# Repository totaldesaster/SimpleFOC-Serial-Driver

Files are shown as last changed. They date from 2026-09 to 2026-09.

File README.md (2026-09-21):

# SimpleFOC-Serial-Driver
Advanced dual BLDC driver modules, designed to be controlled from a trajectory controller over a serial connection. Features a compact high power design with two stacked PCBs. While the top PCB focuses on motor driving, the bottom PCB serves as the controller and interface board.



Work in Progress, will be updated as more information and tests become available!

# Base Board (RP2350)
BaseBoard
The base board acts as a carrier for power boards and contains the microcontroller, communications and programming interfaces, and power input circuits. It shares power with top-mounted driver boards over the standoffs in the mounting holes. It's equipped with:  

- RP2354B, Dual Cortex-M33 or RISC-V processors at 150MHz
- THVD1424, communication over RS-485 or RS-422 at up to 10MHz
- Input voltage and current monitoring
- Two Encoder connections with I2C interfaces
- External connections to power, RS-422/485 and TTL UART

# Dual BLDC driver board
DualShield
Featuring two BLDC drivers and an auxiliary circuit to dissipate braking energy, the Dual BLDC board is able to drive low to medium power BLDCs at up to 7 amps. Peak currents may be far higher (not yet tested).  

- Two DRV8323S (SPI configuration) or DRV8323H (hard-coded) BLDC drivers
- Medium-Power HSBB6066 MOSFETs
- Onboard brake resistor able to dissipate ~5 watts
- Onboard thermistor to measure the board's temperature

# High-Power BLDC driver board
PowerShield
Equipped with bigger MOSFETs and connection points for an external brake resistor and power supply, this board is able to drive a much higher power motor.  

- DRV8323S BLDC driver
- 160A rated Infineon OptiMOS MOSFETs, continuous power limited by thermals (not yet tested)$
- Auxiliary output for external brake resistor
- Onboard thermistor to measure the board's temperature

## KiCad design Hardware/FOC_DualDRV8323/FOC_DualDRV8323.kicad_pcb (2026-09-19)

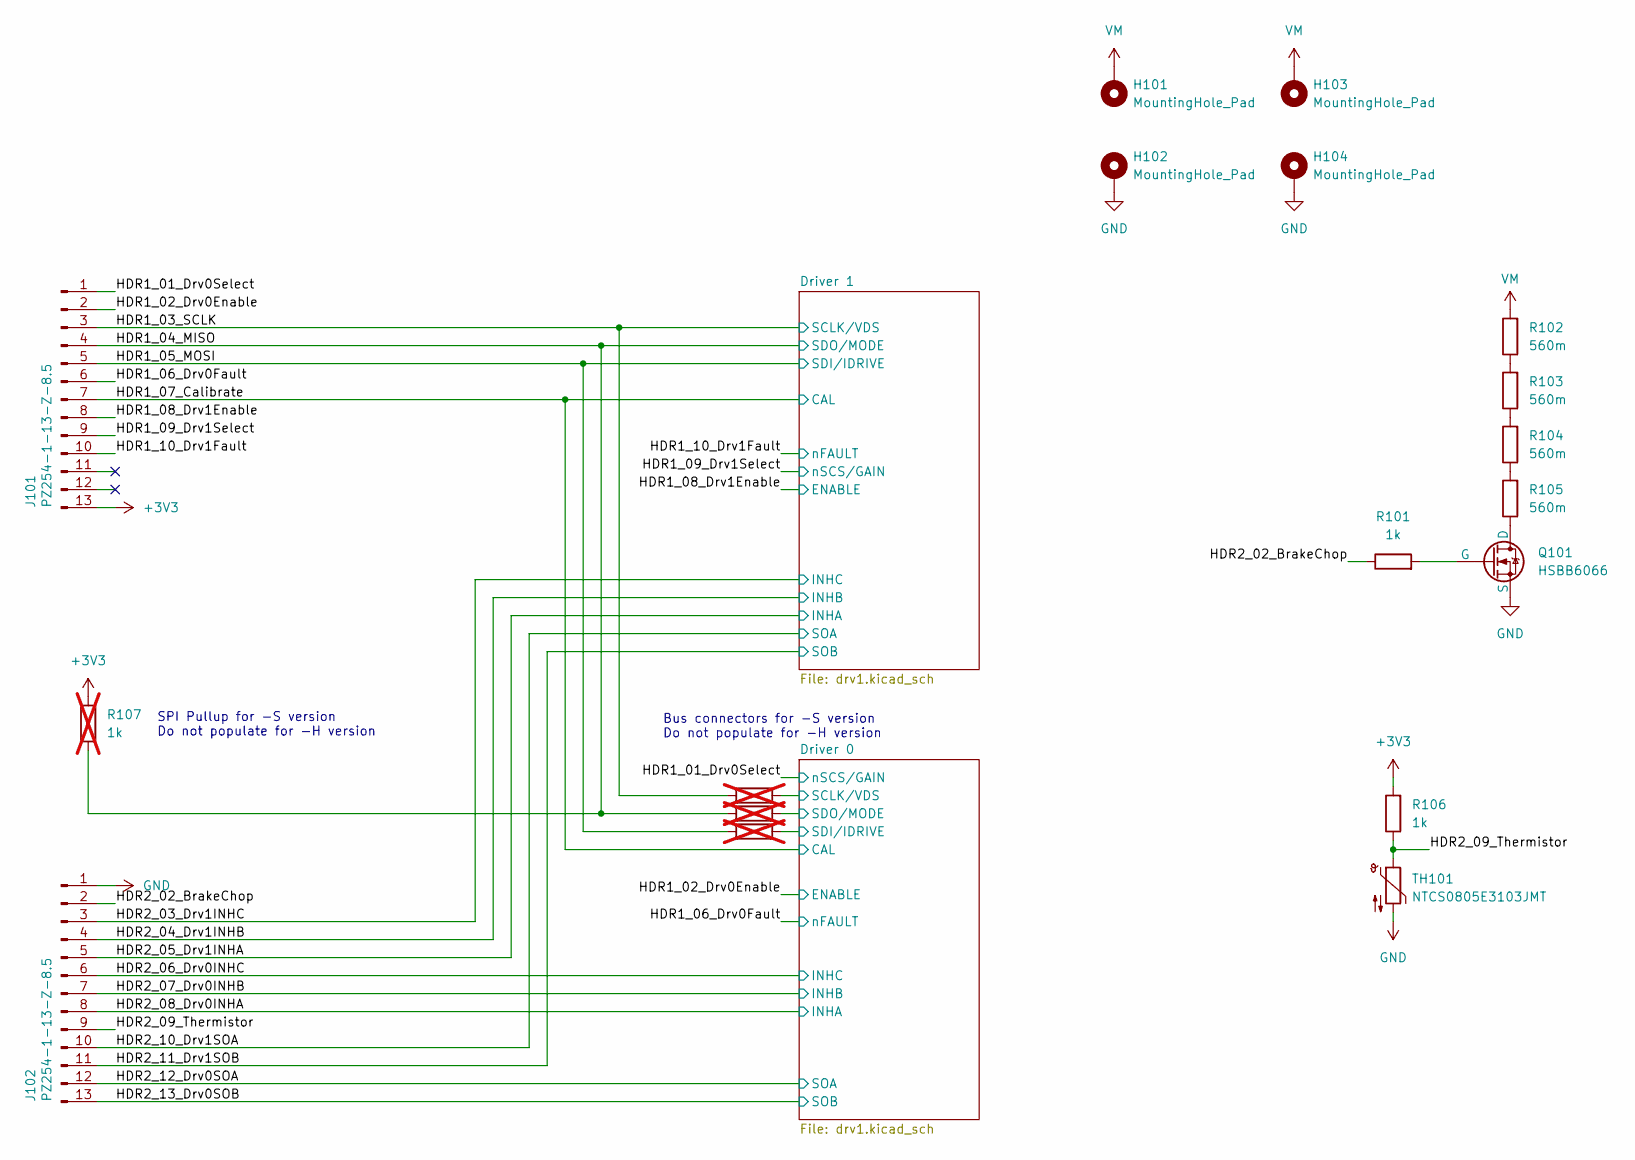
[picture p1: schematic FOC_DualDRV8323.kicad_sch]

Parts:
H101, H102, H103, H104: MountingHole_Pad; MountingHole_3.2mm_M3_Pad_Via
J101: PZ254-1-13-Z-8.5; PinHeader_1x13_P2.54mm_Vertical_SMD_Pin1Left
J102: PZ254-1-13-Z-8.5; PinHeader_1x13_P2.54mm_Vertical_SMD_Pin1Right
Q101: HSBB6066; VSON-8_3.3x3.3mm_P0.65mm_NexFET
R101, R106: 1k; R_0603_1608Metric
R102, R103, R104, R105: 560m; R_2512_6332Metric
R107: 1k; R_0603_1608Metric; not fitted
R108, R109, R110: 0; R_0603_1608Metric; not fitted
TH101: NTCS0805E3103JMT; R_0805_2012Metric

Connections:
+3V3: J101.13, R106.2, R107.2
/Driver 0/SCLK/VDS: R108.1; also elsewhere on the board
/Driver 0/SDI/IDRIVE: R110.1; also elsewhere on the board
/Driver 0/SDO/MODE: R109.1; also elsewhere on the board
/HDR1_01_Drv0Select: J101.1; also elsewhere on the board
/HDR1_02_Drv0Enable: J101.2; also elsewhere on the board
/HDR1_03_SCLK: J101.3, R108.2; also elsewhere on the board
/HDR1_04_MISO: J101.4, R107.1, R109.2; also elsewhere on the board
/HDR1_05_MOSI: J101.5, R110.2; also elsewhere on the board
/HDR1_06_Drv0Fault: J101.6; also elsewhere on the board
/HDR1_07_Calibrate: J101.7; also elsewhere on the board
/HDR1_08_Drv1Enable: J101.8; also elsewhere on the board
/HDR1_09_Drv1Select: J101.9; also elsewhere on the board
/HDR1_10_Drv1Fault: J101.10; also elsewhere on the board
/HDR2_02_BrakeChop: J102.2, R101.1
/HDR2_03_Drv1INHC: J102.3; also elsewhere on the board
/HDR2_04_Drv1INHB: J102.4; also elsewhere on the board
/HDR2_05_Drv1INHA: J102.5; also elsewhere on the board
/HDR2_06_Drv0INHC: J102.6; also elsewhere on the board
/HDR2_07_Drv0INHB: J102.7; also elsewhere on the board
/HDR2_08_Drv0INHA: J102.8; also elsewhere on the board
/HDR2_09_Thermistor: J102.9, R106.1, TH101.1
/HDR2_10_Drv1SOA: J102.10; also elsewhere on the board
/HDR2_11_Drv1SOB: J102.11; also elsewhere on the board
/HDR2_12_Drv0SOA: J102.12; also elsewhere on the board
/HDR2_13_Drv0SOB: J102.13; also elsewhere on the board
GND: H102.1 (1_1), H104.1 (1_1), J102.1, Q101.3 (S), TH101.2; also elsewhere on the board
unnamed: Q101.1 (D), R105.1
unnamed: Q101.2 (G), R101.2
unnamed: R102.1, R103.2
unnamed: R103.1, R104.2
unnamed: R104.1, R105.2
VM: H101.1 (1_1), H103.1 (1_1), R102.2; also elsewhere on the board

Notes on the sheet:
Bus connectors for -S version Do not populate for -H version
SPI Pullup for -S version Do not populate for -H version

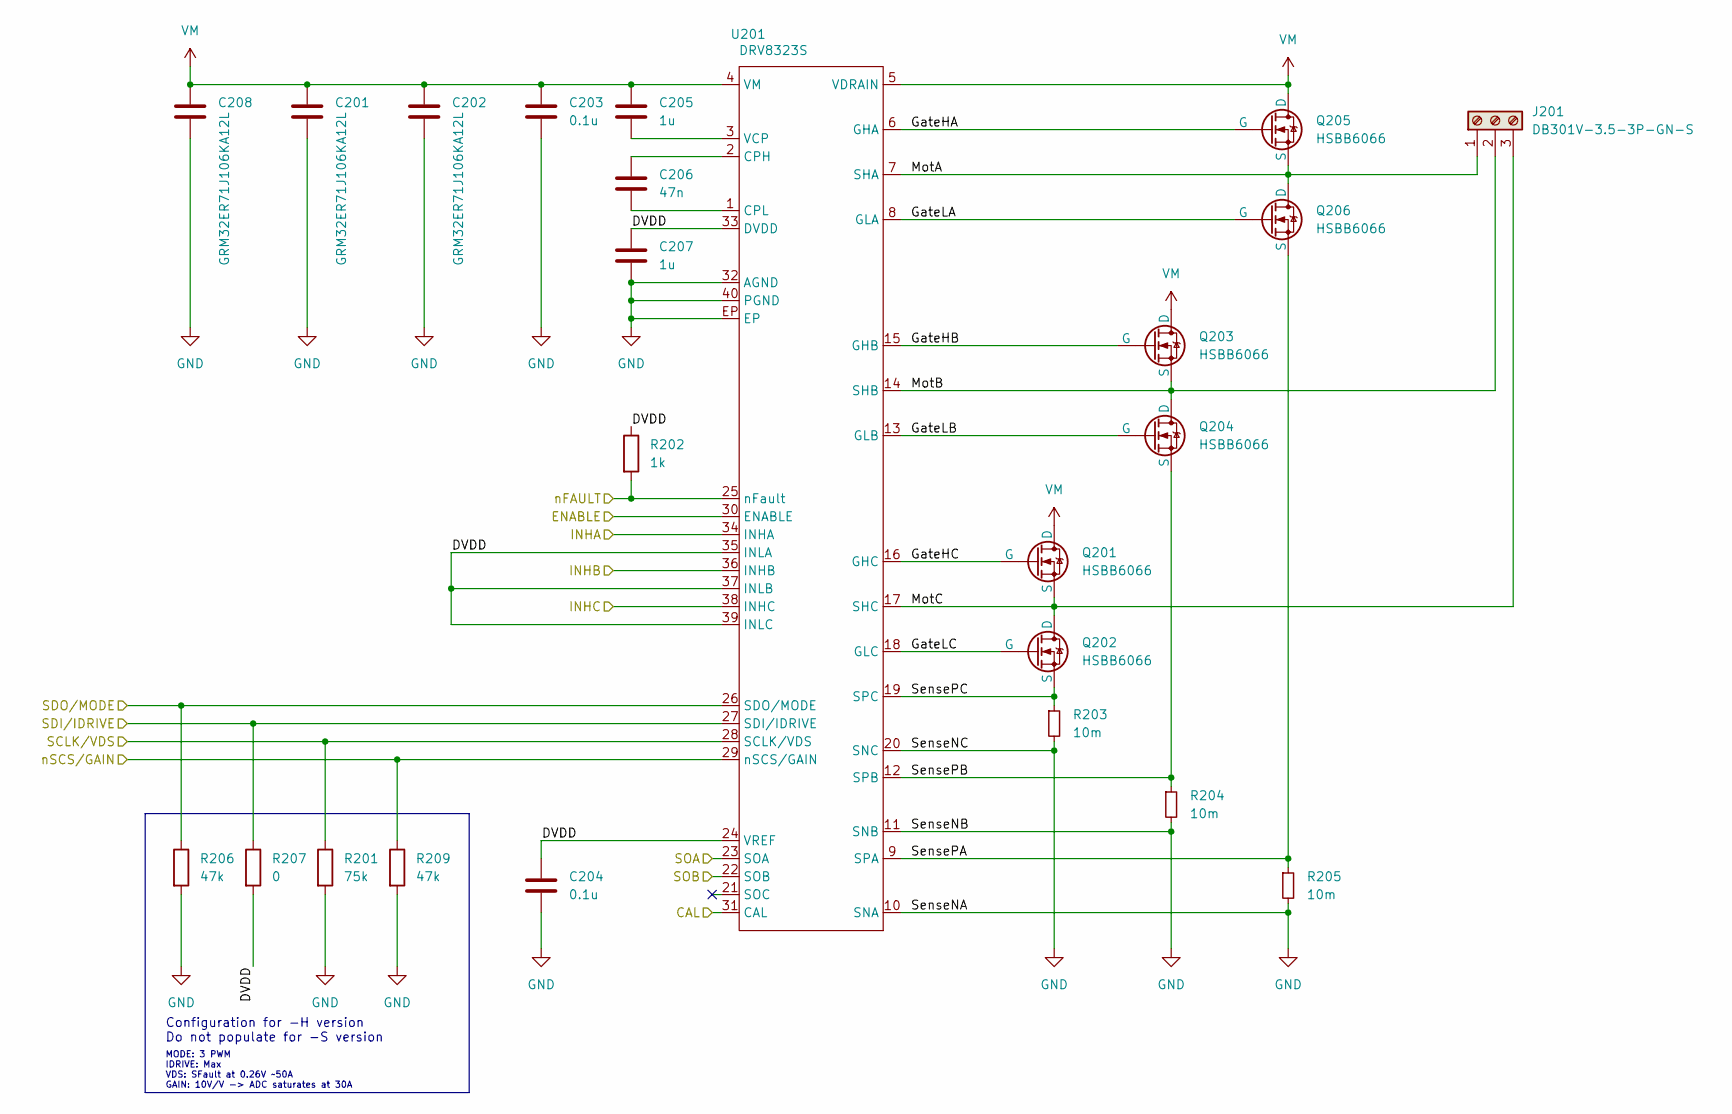
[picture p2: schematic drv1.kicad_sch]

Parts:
C201, C202, C208: GRM32ER71J106KA12L; C_1210_3225Metric
C203, C204: 0.1u; C_0603_1608Metric
C205, C207: 1u; C_0603_1608Metric
C206: 47n; C_0603_1608Metric
J201: DB301V-3.5-3P-GN-S; TerminalBlock_Phoenix_PT-1,5-3-3.5-H_1x03_P3.50mm_Horizontal
Q201, Q202, Q203, Q204, Q205, Q206: HSBB6066; VSON-8_3.3x3.3mm_P0.65mm_NexFET
R201: 75k; R_0603_1608Metric
R202: 1k; R_0603_1608Metric
R203, R204, R205: 10m; R_1206_3216Metric
R206, R209: 47k; R_0603_1608Metric
R207: 0; R_0603_1608Metric
U201: DRV8323S; Texas_RHA0040E_VQFN-40-1EP_6x6mm_P0.5mm_EP3.52x2.62mm

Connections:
/Driver 0/DVDD: C204.1, C207.1, R202.1, R207.2, U201.24 (VREF), U201.33 (DVDD), U201.35 (INLA), U201.37 (INLB), U201.39 (INLC)
/Driver 0/GateHA: Q205.2 (G), U201.6 (GHA)
/Driver 0/GateHB: Q203.2 (G), U201.15 (GHB)
/Driver 0/GateHC: Q201.2 (G), U201.16 (GHC)
/Driver 0/GateLA: Q206.2 (G), U201.8 (GLA)
/Driver 0/GateLB: Q204.2 (G), U201.13 (GLB)
/Driver 0/GateLC: Q202.2 (G), U201.18 (GLC)
/Driver 0/MotA: J201.1, Q205.3 (S), Q206.1 (D), U201.7 (SHA)
/Driver 0/MotB: J201.2, Q203.3 (S), Q204.1 (D), U201.14 (SHB)
/Driver 0/MotC: J201.3, Q201.3 (S), Q202.1 (D), U201.17 (SHC)
/Driver 0/SCLK/VDS: R201.1, U201.28 (SCLK/VDS); also elsewhere on the board
/Driver 0/SDI/IDRIVE: R207.1, U201.27 (SDI/IDRIVE); also elsewhere on the board
/Driver 0/SDO/MODE: R206.1, U201.26 (SDO/MODE); also elsewhere on the board
/Driver 0/SensePA: Q206.3 (S), R205.1, U201.9 (SPA)
/Driver 0/SensePB: Q204.3 (S), R204.1, U201.12 (SPB)
/Driver 0/SensePC: Q202.3 (S), R203.1, U201.19 (SPC)
/HDR1_01_Drv0Select: R209.1, U201.29 (nSCS/GAIN); also elsewhere on the board
/HDR1_02_Drv0Enable: U201.30 (ENABLE); also elsewhere on the board
/HDR1_06_Drv0Fault: R202.2, U201.25 (nFault); also elsewhere on the board
/HDR1_07_Calibrate: U201.31 (CAL); also elsewhere on the board
/HDR2_06_Drv0INHC: U201.38 (INHC); also elsewhere on the board
/HDR2_07_Drv0INHB: U201.36 (INHB); also elsewhere on the board
/HDR2_08_Drv0INHA: U201.34 (INHA); also elsewhere on the board
/HDR2_12_Drv0SOA: U201.23 (SOA); also elsewhere on the board
/HDR2_13_Drv0SOB: U201.22 (SOB); also elsewhere on the board
GND: C201.2, C202.2, C203.2, C204.2, C207.2, C208.2, R201.2, R203.2, R204.2, R205.2, R206.2, R209.2, U201.10 (SNA), U201.11 (SNB), U201.20 (SNC), U201.32 (AGND), U201.40 (PGND), U201.EP; also elsewhere on the board
unnamed: C206.1, U201.2 (CPH)
unnamed: C206.2, U201.1 (CPL)
unnamed: C205.2, U201.3 (VCP)
VM: C201.1, C202.1, C203.1, C205.1, C208.1, Q201.1 (D), Q203.1 (D), Q205.1 (D), U201.4 (VM), U201.5 (VDRAIN); also elsewhere on the board

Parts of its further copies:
C301, C302, C308: GRM32ER71J106KA12L; C_1210_3225Metric
C303, C304: 0.1u; C_0603_1608Metric
C305, C307: 1u; C_0603_1608Metric
C306: 47n; C_0603_1608Metric
J301: DB301V-3.5-3P-GN-S; TerminalBlock_Phoenix_PT-1,5-3-3.5-H_1x03_P3.50mm_Horizontal
Q301, Q302, Q303, Q304, Q305, Q306: HSBB6066; VSON-8_3.3x3.3mm_P0.65mm_NexFET
R301: 75k; R_0603_1608Metric
R302: 1k; R_0603_1608Metric
R303, R304, R305: 10m; R_1206_3216Metric
R306, R309: 47k; R_0603_1608Metric
R307: 0; R_0603_1608Metric
U301: DRV8323S; Texas_RHA0040E_VQFN-40-1EP_6x6mm_P0.5mm_EP3.52x2.62mm

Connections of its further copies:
/Driver 1/DVDD: C304.1, C307.1, R302.1, R307.2, U301.24 (VREF), U301.33 (DVDD), U301.35 (INLA), U301.37 (INLB), U301.39 (INLC)
/Driver 1/GateHA: Q305.2 (G), U301.6 (GHA)
/Driver 1/GateHB: Q303.2 (G), U301.15 (GHB)
/Driver 1/GateHC: Q301.2 (G), U301.16 (GHC)
/Driver 1/GateLA: Q306.2 (G), U301.8 (GLA)
/Driver 1/GateLB: Q304.2 (G), U301.13 (GLB)
/Driver 1/GateLC: Q302.2 (G), U301.18 (GLC)
/Driver 1/MotA: J301.1, Q305.3 (S), Q306.1 (D), U301.7 (SHA)
/Driver 1/MotB: J301.2, Q303.3 (S), Q304.1 (D), U301.14 (SHB)
/Driver 1/MotC: J301.3, Q301.3 (S), Q302.1 (D), U301.17 (SHC)
/Driver 1/SensePA: Q306.3 (S), R305.1, U301.9 (SPA)
/Driver 1/SensePB: Q304.3 (S), R304.1, U301.12 (SPB)
/Driver 1/SensePC: Q302.3 (S), R303.1, U301.19 (SPC)
/HDR1_03_SCLK: R301.1, U301.28 (SCLK/VDS); also elsewhere on the board
/HDR1_04_MISO: R306.1, U301.26 (SDO/MODE); also elsewhere on the board
/HDR1_05_MOSI: R307.1, U301.27 (SDI/IDRIVE); also elsewhere on the board
/HDR1_07_Calibrate: U301.31 (CAL); also elsewhere on the board
/HDR1_08_Drv1Enable: U301.30 (ENABLE); also elsewhere on the board
/HDR1_09_Drv1Select: R309.1, U301.29 (nSCS/GAIN); also elsewhere on the board
/HDR1_10_Drv1Fault: R302.2, U301.25 (nFault); also elsewhere on the board
/HDR2_03_Drv1INHC: U301.38 (INHC); also elsewhere on the board
/HDR2_04_Drv1INHB: U301.36 (INHB); also elsewhere on the board
/HDR2_05_Drv1INHA: U301.34 (INHA); also elsewhere on the board
/HDR2_10_Drv1SOA: U301.23 (SOA); also elsewhere on the board
/HDR2_11_Drv1SOB: U301.22 (SOB); also elsewhere on the board
GND: C301.2, C302.2, C303.2, C304.2, C307.2, C308.2, R301.2, R303.2, R304.2, R305.2, R306.2, R309.2, U301.10 (SNA), U301.11 (SNB), U301.20 (SNC), U301.32 (AGND), U301.40 (PGND); also elsewhere on the board
unnamed: C306.1, U301.2 (CPH)
unnamed: C306.2, U301.1 (CPL)
unnamed: C305.2, U301.3 (VCP)
VM: C301.1, C302.1, C303.1, C305.1, C308.1, Q301.1 (D), Q303.1 (D), Q305.1 (D), U301.4 (VM), U301.5 (VDRAIN); also elsewhere on the board

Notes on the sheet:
Configuration for -H version Do not populate for -S version
MODE: 3 PWM IDRIVE: Max VDS: SFault at 0.26V ~50A GAIN: 10V/V -> ADC saturates at 30A

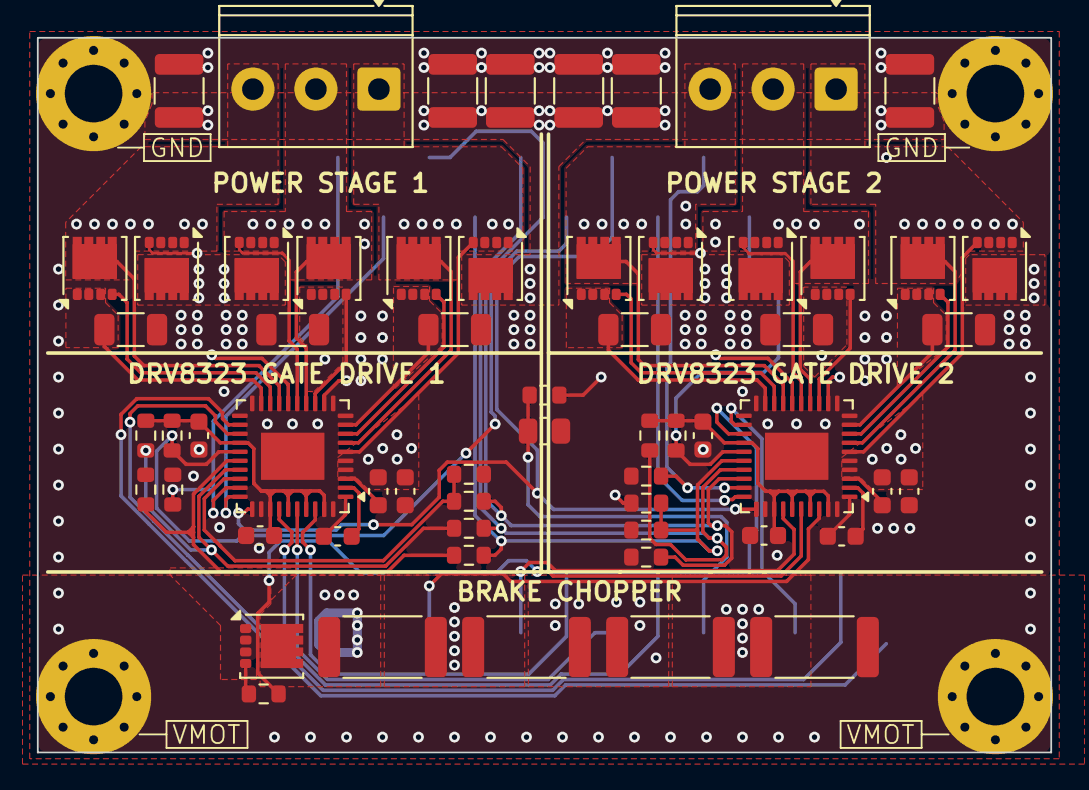
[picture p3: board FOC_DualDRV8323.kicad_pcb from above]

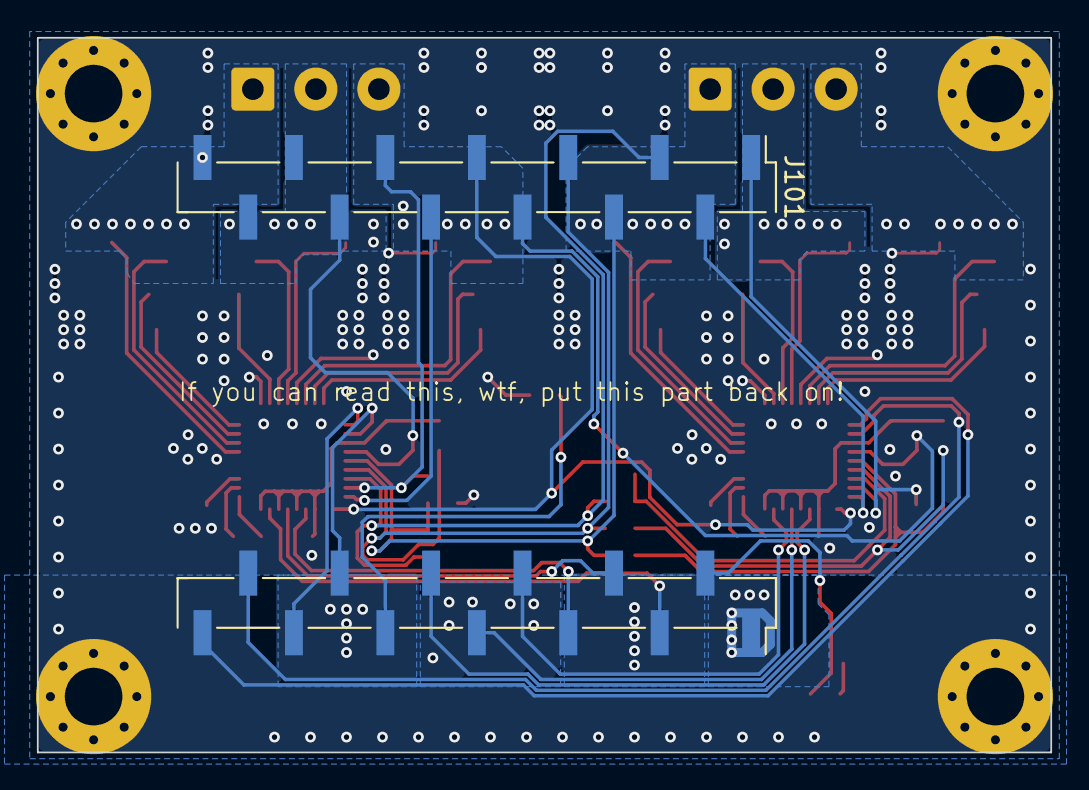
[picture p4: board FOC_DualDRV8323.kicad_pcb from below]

Board: 4 copper layers, 56.3 x 39.7 mm, 66 parts (2 on the bottom side), 65 nets.

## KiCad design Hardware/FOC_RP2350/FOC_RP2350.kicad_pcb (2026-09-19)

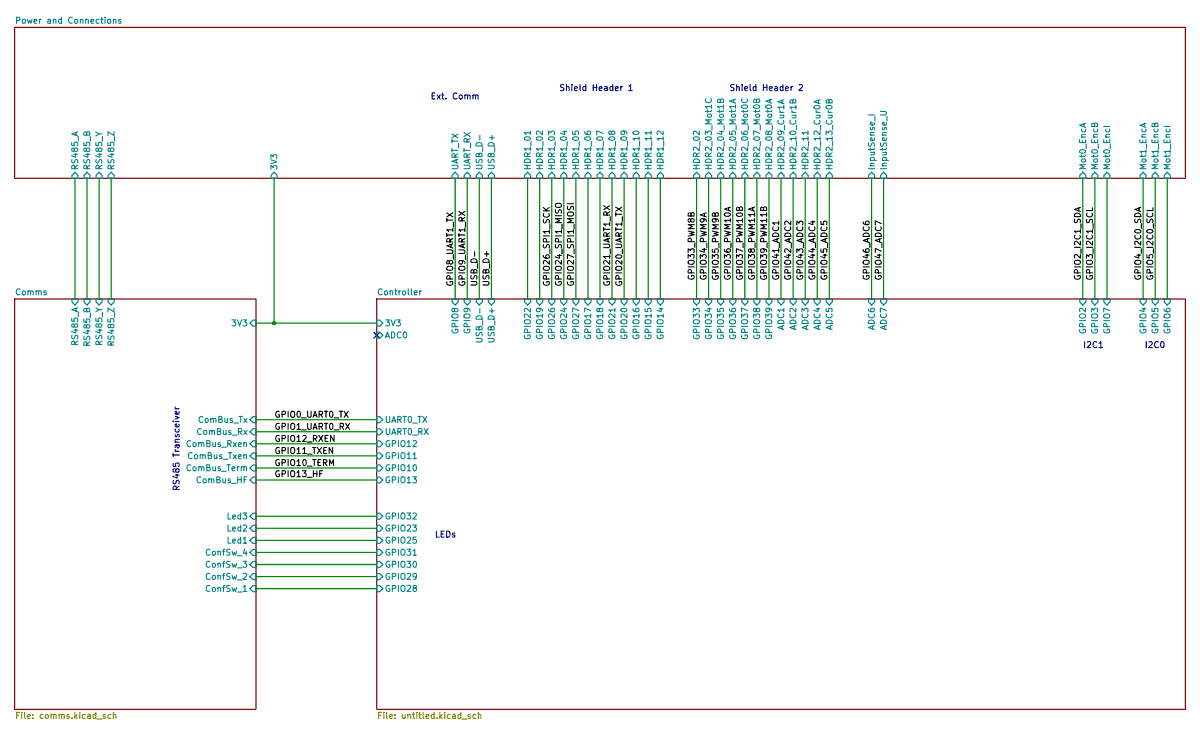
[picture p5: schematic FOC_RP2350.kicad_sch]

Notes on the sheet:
I2C1
I2C0
Shield Header 2
Ext. Comm
LEDs
RS485 Transceiver
Shield Header 1

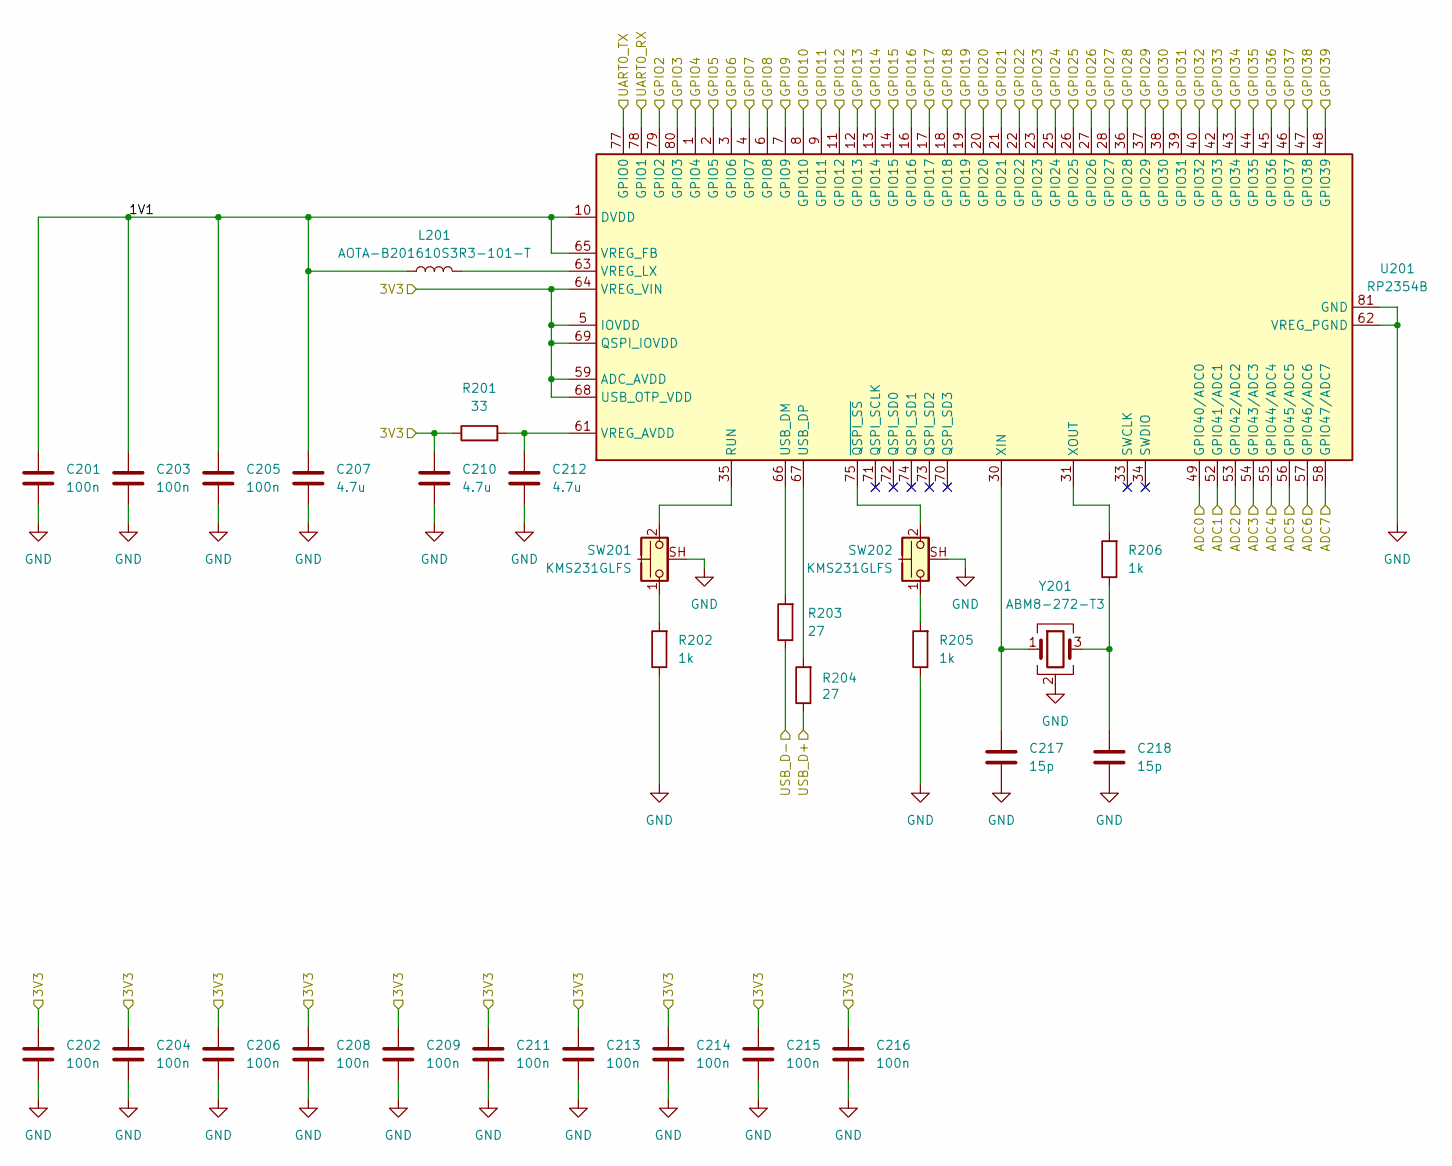
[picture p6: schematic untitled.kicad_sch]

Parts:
C201, C202, C203, C204, C205, C206, C208, C209, C211, C213, C214, C215, C216: 100n; C_0402_1005Metric
C207, C210, C212: 4.7u; C_0402_1005Metric
C217, C218: 15p; C_0402_1005Metric
L201: AOTA-B201610S3R3-101-T; L_Changjiang_FTC201607S
R201: 33; R_0402_1005Metric
R202, R205: 1k; R_0805_2012Metric
R203, R204: 27; R_0603_1608Metric
R206: 1k; R_0402_1005Metric
SW201, SW202: KMS231GLFS; SW_SPST_CK_KMS2xxGP
U201: RP2354B; QFN-80-1EP_10x10mm_P0.4mm_EP3.4x3.4mm
Y201: ABM8-272-T3; Crystal_SMD_Abracon_ABM8G-4Pin_3.2x2.5mm

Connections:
/Comms/3V3: C202.1, C204.1, C206.1, C208.1, C209.1, C210.1, C211.1, C213.1, C214.1, C215.1, C216.1, R201.1, U201.5 (IOVDD), U201.15 (IOVDD), U201.24 (IOVDD), U201.29 (IOVDD), U201.41 (IOVDD), U201.50 (IOVDD), U201.59 (ADC_AVDD), U201.60 (IOVDD), U201.64 (VREG_VIN), U201.68 (USB_OTP_VDD), U201.69 (QSPI_IOVDD), U201.76 (IOVDD); also elsewhere on the board
/Comms/ComBus_HF: U201.12 (GPIO13); also elsewhere on the board
/Comms/ConfSw_1: U201.36 (GPIO28); also elsewhere on the board
/Comms/ConfSw_2: U201.37 (GPIO29); also elsewhere on the board
/Comms/ConfSw_3: U201.38 (GPIO30); also elsewhere on the board
/Comms/ConfSw_4: U201.39 (GPIO31); also elsewhere on the board
/Comms/Led1: U201.26 (GPIO25); also elsewhere on the board
/Comms/Led2: U201.23 (GPIO23); also elsewhere on the board
/Comms/Led3: U201.40 (GPIO32); also elsewhere on the board
/Controller/1V1: C201.1, C203.1, C205.1, C207.1, L201.1, U201.10 (DVDD), U201.32 (DVDD), U201.51 (DVDD), U201.65 (VREG_FB)
/Controller/ADC0: U201.49 (GPIO40/ADC0)
/Controller/GPIO6: U201.3 (GPIO6); also elsewhere on the board
/Controller/GPIO7: U201.4 (GPIO7); also elsewhere on the board
/Controller/GPIO14: U201.13 (GPIO14); also elsewhere on the board
/Controller/GPIO15: U201.14 (GPIO15); also elsewhere on the board
/Controller/GPIO16: U201.16 (GPIO16); also elsewhere on the board
/Controller/GPIO17: U201.17 (GPIO17); also elsewhere on the board
/Controller/GPIO18: U201.18 (GPIO18); also elsewhere on the board
/Controller/GPIO19: U201.19 (GPIO19); also elsewhere on the board
/Controller/GPIO22: U201.22 (GPIO22); also elsewhere on the board
/GPIO0_UART0_TX: U201.77 (GPIO0); also elsewhere on the board
/GPIO1_UART0_RX: U201.78 (GPIO1); also elsewhere on the board
/GPIO2_I2C1_SDA: U201.79 (GPIO2); also elsewhere on the board
/GPIO3_I2C1_SCL: U201.80 (GPIO3); also elsewhere on the board
/GPIO4_I2C0_SDA: U201.1 (GPIO4); also elsewhere on the board
/GPIO5_I2C0_SCL: U201.2 (GPIO5); also elsewhere on the board
/GPIO8_UART1_TX: U201.6 (GPIO8); also elsewhere on the board
/GPIO9_UART1_RX: U201.7 (GPIO9); also elsewhere on the board
/GPIO10_TERM: U201.8 (GPIO10); also elsewhere on the board
/GPIO11_TXEN: U201.9 (GPIO11); also elsewhere on the board
/GPIO12_RXEN: U201.11 (GPIO12); also elsewhere on the board
/GPIO20_UART1_TX: U201.20 (GPIO20); also elsewhere on the board
/GPIO21_UART1_RX: U201.21 (GPIO21); also elsewhere on the board
/GPIO24_SPI1_MISO: U201.25 (GPIO24); also elsewhere on the board
/GPIO26_SPI1_SCK: U201.27 (GPIO26); also elsewhere on the board
/GPIO27_SPI1_MOSI: U201.28 (GPIO27); also elsewhere on the board
/GPIO33_PWM8B: U201.42 (GPIO33); also elsewhere on the board
/GPIO34_PWM9A: U201.43 (GPIO34); also elsewhere on the board
/GPIO35_PWM9B: U201.44 (GPIO35); also elsewhere on the board
/GPIO36_PWM10A: U201.45 (GPIO36); also elsewhere on the board
/GPIO37_PWM10B: U201.46 (GPIO37); also elsewhere on the board
/GPIO38_PWM11A: U201.47 (GPIO38); also elsewhere on the board
/GPIO39_PWM11B: U201.48 (GPIO39); also elsewhere on the board
/GPIO41_ADC1: U201.52 (GPIO41/ADC1); also elsewhere on the board
/GPIO42_ADC2: U201.53 (GPIO42/ADC2); also elsewhere on the board
/GPIO43_ADC3: U201.54 (GPIO43/ADC3); also elsewhere on the board
/GPIO44_ADC4: U201.55 (GPIO44/ADC4); also elsewhere on the board
/GPIO45_ADC5: U201.56 (GPIO45/ADC5); also elsewhere on the board
/GPIO46_ADC6: U201.57 (GPIO46/ADC6); also elsewhere on the board
/GPIO47_ADC7: U201.58 (GPIO47/ADC7); also elsewhere on the board
/USB_D+: R204.1; also elsewhere on the board
/USB_D-: R203.1; also elsewhere on the board
GND: C201.2, C202.2, C203.2, C204.2, C205.2, C206.2, C207.2, C208.2, C209.2, C210.2, C211.2, C212.2, C213.2, C214.2, C215.2, C216.2, C217.2, C218.2, R202.1, R205.1, SW201.SH (B), SW202.SH (B), U201.62 (VREG_PGND), U201.81 (GND), Y201.2 (G), Y201.4 (G); also elsewhere on the board
unnamed: C218.1, R206.1, Y201.3
unnamed: R202.2, SW201.1
unnamed: R205.2, SW202.1
unnamed: SW201.2, U201.35 (RUN)
unnamed: R203.2, U201.66 (USB_DM)
unnamed: R204.2, U201.67 (USB_DP)
unnamed: C212.1, R201.2, U201.61 (VREG_AVDD)
unnamed: L201.2, U201.63 (VREG_LX)
unnamed: C217.1, U201.30 (XIN), Y201.1
unnamed: R206.2, U201.31 (XOUT)
unnamed: SW202.2, U201.75 (~QSPI_SS)

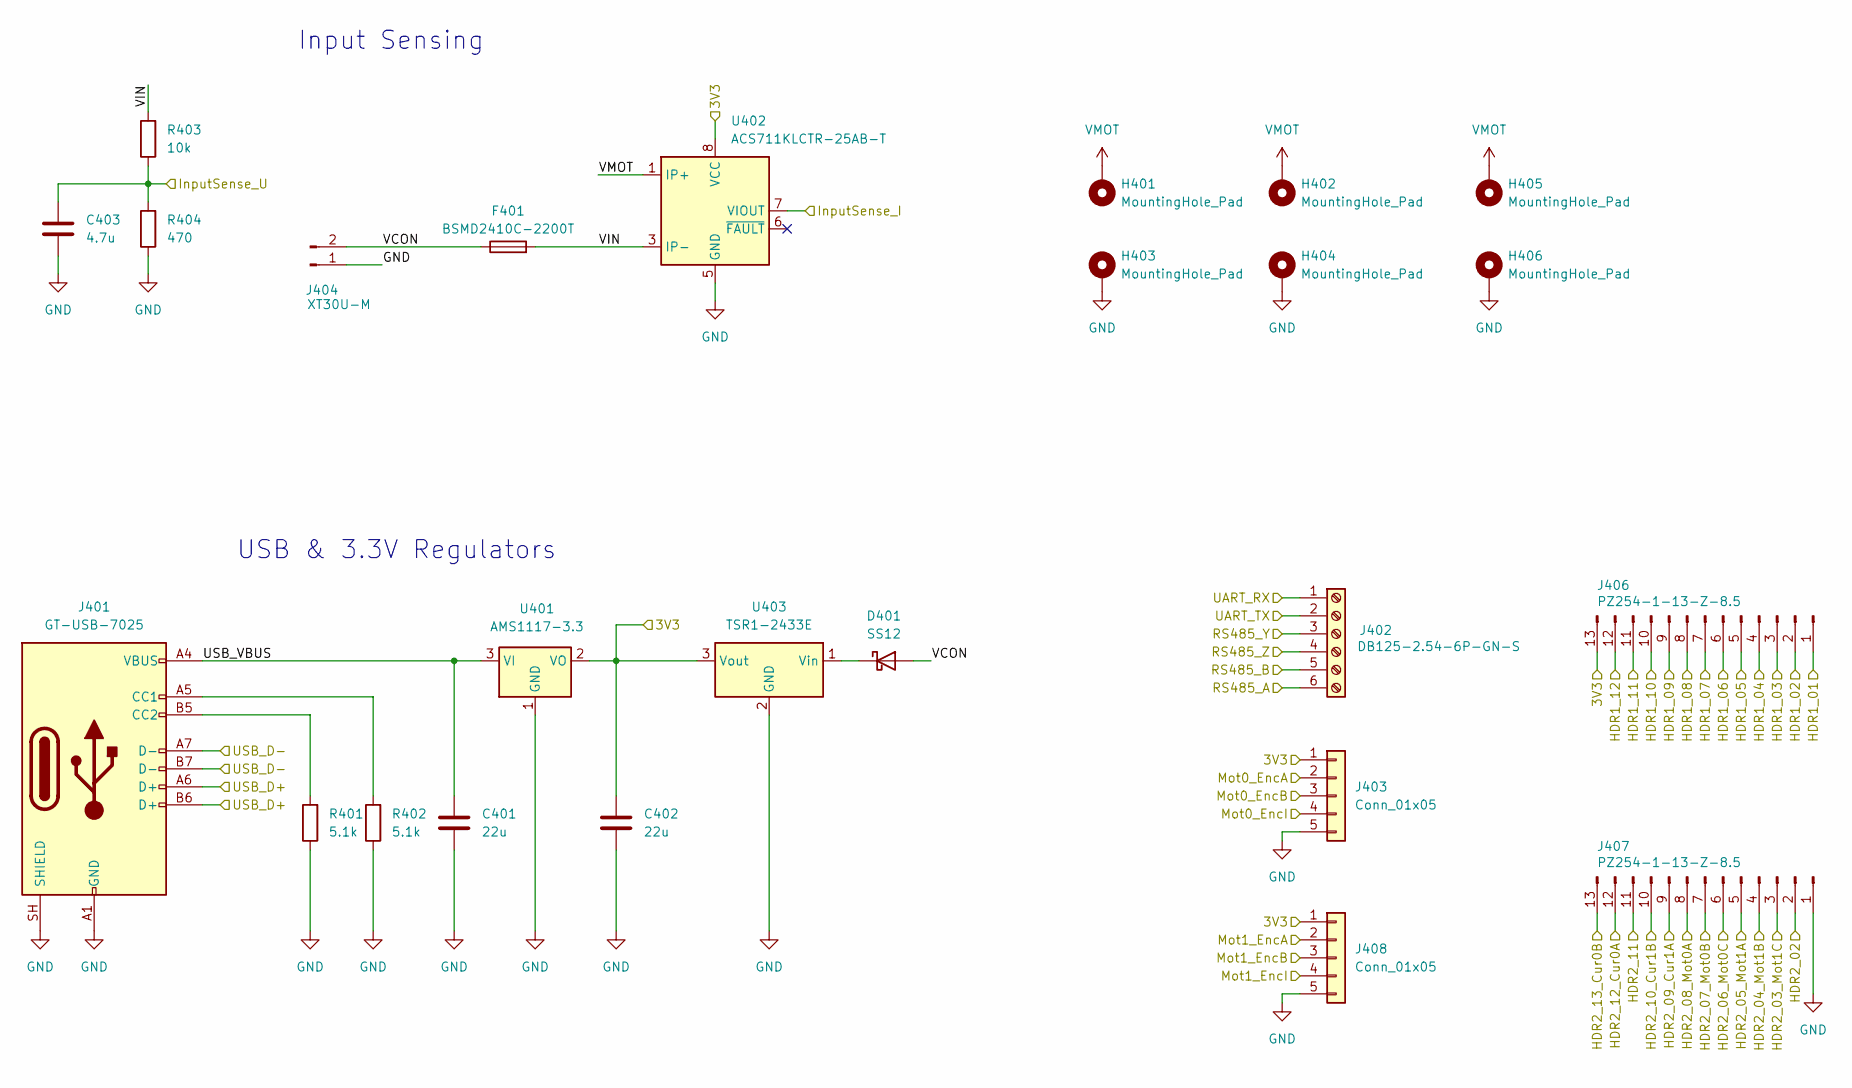
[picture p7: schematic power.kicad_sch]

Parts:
C401, C402: 22u; C_0805_2012Metric
C403: 4.7u; C_0402_1005Metric
D401: SS12; D_SMA
F401: BSMD2410C-2200T; Fuse_2512_6332Metric_Pad1.52x3.35mm_HandSolder
H401, H402, H403, H404: MountingHole_Pad; MountingHole_3.2mm_M3_Pad_Via
H405, H406: MountingHole_Pad; TestPoint_THTPad_D2.0mm_Drill1.0mm
J401: GT-USB-7025; USB_C_Receptacle_G-Switch_GT-USB-7025
J402: DB125-2.54-6P-GN-S; TerminalBlock_Phoenix_MPT-0,5-6-2.54_1x06_P2.54mm_Horizontal
J403, J408: Conn_01x05; JST_XH_B5B-XH-A_1x05_P2.50mm_Vertical
J404: XT30U-M; AMASS_XT30U-F_1x02_P5.0mm_Vertical
J406, J407: PZ254-1-13-Z-8.5; PinHeader_1x13_P2.54mm_Vertical
R401, R402: 5.1k; R_0805_2012Metric
R403: 10k; R_0805_2012Metric
R404: 470; R_0805_2012Metric
U401: AMS1117-3.3; SOT-223-3_TabPin2
U402: ACS711KLCTR-25AB-T; SOIC-8_3.9x4.9mm_P1.27mm
U403: TSR1-2433E; Converter_DCDC_TRACO_TSR1-xxxxE_THT

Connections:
/Comms/3V3: C402.1, J403.1, J406.13, J408.1, U401.2 (VO), U402.8 (VCC), U403.3 (Vout); also elsewhere on the board
/Comms/RS485_A: J402.6; also elsewhere on the board
/Comms/RS485_B: J402.5; also elsewhere on the board
/Comms/RS485_Y: J402.3; also elsewhere on the board
/Comms/RS485_Z: J402.4; also elsewhere on the board
/Controller/GPIO6: J408.4; also elsewhere on the board
/Controller/GPIO7: J403.4; also elsewhere on the board
/Controller/GPIO14: J406.12; also elsewhere on the board
/Controller/GPIO15: J406.11; also elsewhere on the board
/Controller/GPIO16: J406.10; also elsewhere on the board
/Controller/GPIO17: J406.6; also elsewhere on the board
/Controller/GPIO18: J406.7; also elsewhere on the board
/Controller/GPIO19: J406.2; also elsewhere on the board
/Controller/GPIO22: J406.1; also elsewhere on the board
/GPIO2_I2C1_SDA: J403.2; also elsewhere on the board
/GPIO3_I2C1_SCL: J403.3; also elsewhere on the board
/GPIO4_I2C0_SDA: J408.2; also elsewhere on the board
/GPIO5_I2C0_SCL: J408.3; also elsewhere on the board
/GPIO8_UART1_TX: J402.2; also elsewhere on the board
/GPIO9_UART1_RX: J402.1; also elsewhere on the board
/GPIO20_UART1_TX: J406.9; also elsewhere on the board
/GPIO21_UART1_RX: J406.8; also elsewhere on the board
/GPIO24_SPI1_MISO: J406.4; also elsewhere on the board
/GPIO26_SPI1_SCK: J406.3; also elsewhere on the board
/GPIO27_SPI1_MOSI: J406.5; also elsewhere on the board
/GPIO33_PWM8B: J407.2; also elsewhere on the board
/GPIO34_PWM9A: J407.3; also elsewhere on the board
/GPIO35_PWM9B: J407.4; also elsewhere on the board
/GPIO36_PWM10A: J407.5; also elsewhere on the board
/GPIO37_PWM10B: J407.6; also elsewhere on the board
/GPIO38_PWM11A: J407.7; also elsewhere on the board
/GPIO39_PWM11B: J407.8; also elsewhere on the board
/GPIO41_ADC1: J407.9; also elsewhere on the board
/GPIO42_ADC2: J407.10; also elsewhere on the board
/GPIO43_ADC3: J407.11; also elsewhere on the board
/GPIO44_ADC4: J407.12; also elsewhere on the board
/GPIO45_ADC5: J407.13; also elsewhere on the board
/GPIO46_ADC6: U402.7 (VIOUT); also elsewhere on the board
/GPIO47_ADC7: C403.1, R403.1, R404.2; also elsewhere on the board
/Power and Connections/USB_VBUS: C401.1, J401.A4 (VBUS), J401.A9 (VBUS), J401.B4 (VBUS), J401.B9 (VBUS), U401.3 (VI)
/Power and Connections/VCON: D401.2 (A), F401.1, J404.2
/Power and Connections/VIN: F401.2, R403.2, U402.3 (IP-), U402.4 (IP-)
/USB_D+: J401.A6 (D+), J401.B6 (D+); also elsewhere on the board
/USB_D-: J401.A7 (D-), J401.B7 (D-); also elsewhere on the board
GND: C401.2, C402.2, C403.2, H403.1 (1_1), H404.1 (1_1), H406.1 (1_1), J401.A1 (GND), J401.A12 (GND), J401.B1 (GND), J401.B12 (GND), J401.SH (SHIELD), J403.5, J404.1, J407.1, J408.5, R401.1, R402.1, R404.1, U401.1 (GND), U402.5 (GND), U403.2 (GND); also elsewhere on the board
unnamed: D401.1 (K), U403.1 (Vin)
unnamed: J401.A5 (CC1), R402.2
unnamed: J401.B5 (CC2), R401.2
VMOT: H401.1 (1_1), H402.1 (1_1), H405.1 (1_1), U402.1 (IP+), U402.2 (IP+)

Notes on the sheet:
Input Sensing
USB & 3.3V Regulators

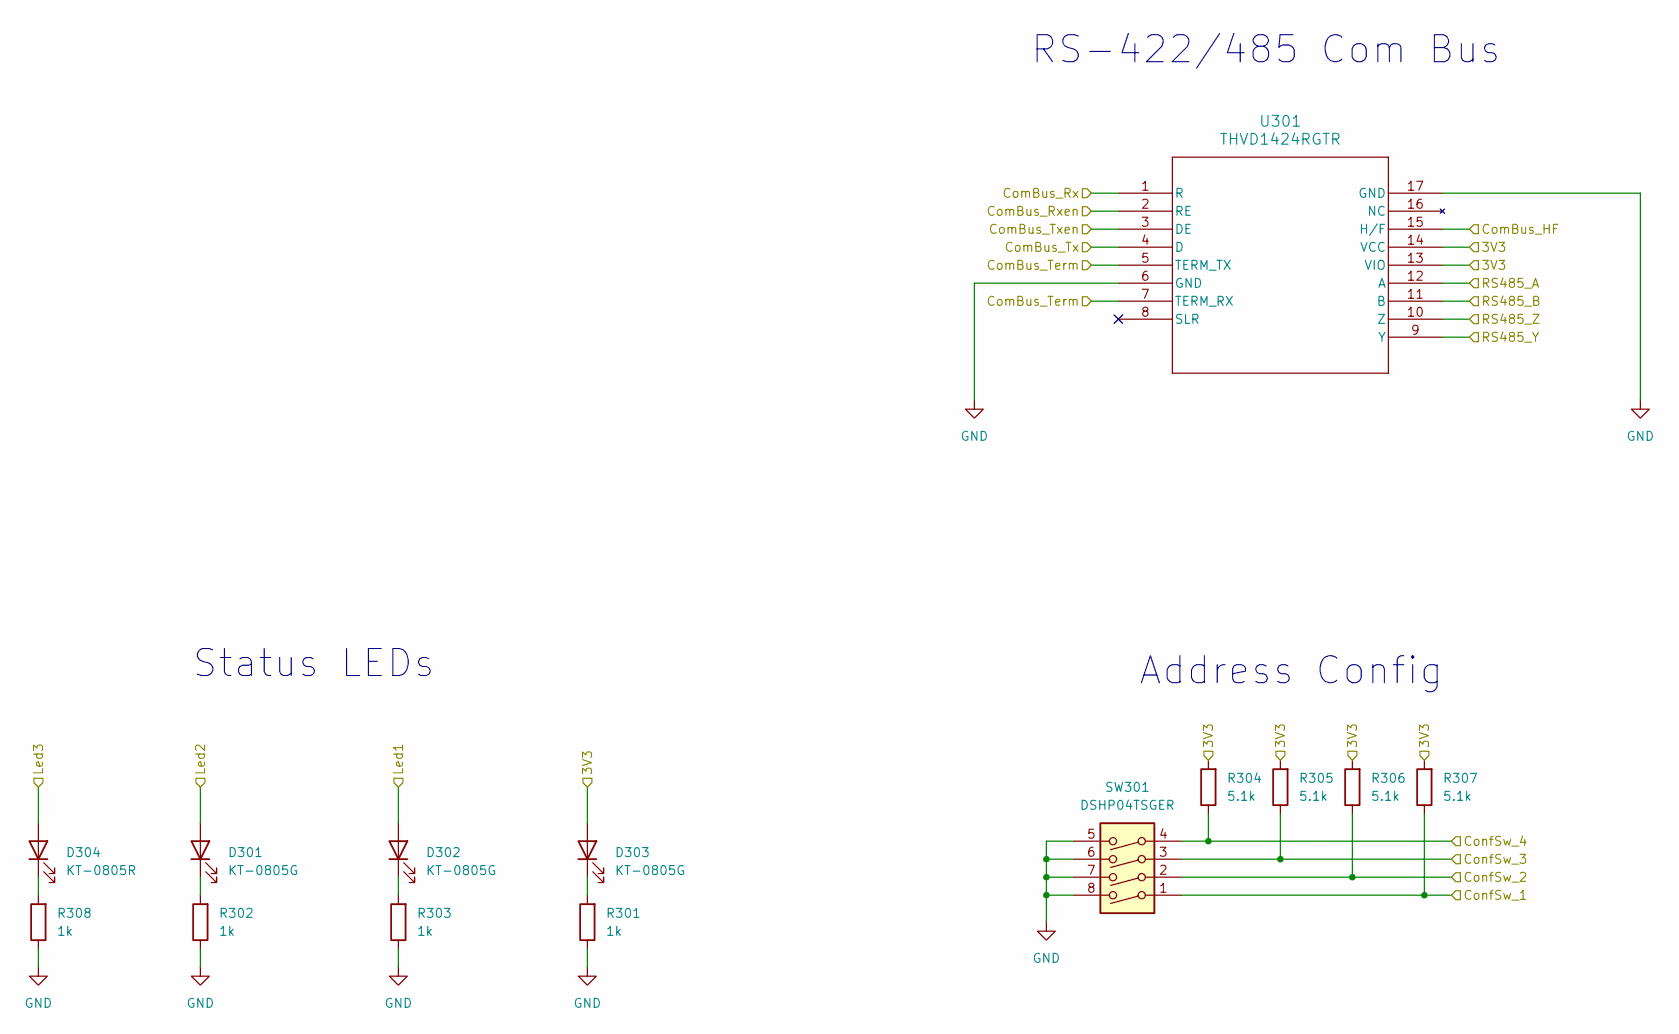
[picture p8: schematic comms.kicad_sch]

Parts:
D301, D302, D303: KT-0805G; LED_0805_2012Metric
D304: KT-0805R; LED_0805_2012Metric
R301, R302, R303, R308: 1k; R_0805_2012Metric
R304, R305, R306, R307: 5.1k; R_0805_2012Metric
SW301: DSHP04TSGER; SW_DIP_SPSTx04_Slide_KingTek_DSHP04TS_W7.62mm_P1.27mm
U301: THVD1424RGTR; QFN_24RGTR_TEX

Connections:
/Comms/3V3: D303.2 (A), R304.2, R305.2, R306.2, R307.2, U301.13 (VIO), U301.14 (VCC); also elsewhere on the board
/Comms/ComBus_HF: U301.15 (H/F); also elsewhere on the board
/Comms/ConfSw_1: R307.1, SW301.1; also elsewhere on the board
/Comms/ConfSw_2: R306.1, SW301.2; also elsewhere on the board
/Comms/ConfSw_3: R305.1, SW301.3; also elsewhere on the board
/Comms/ConfSw_4: R304.1, SW301.4; also elsewhere on the board
/Comms/Led1: D302.2 (A); also elsewhere on the board
/Comms/Led2: D301.2 (A); also elsewhere on the board
/Comms/Led3: D304.2 (A); also elsewhere on the board
/Comms/RS485_A: U301.12 (A); also elsewhere on the board
/Comms/RS485_B: U301.11 (B); also elsewhere on the board
/Comms/RS485_Y: U301.9 (Y); also elsewhere on the board
/Comms/RS485_Z: U301.10 (Z); also elsewhere on the board
/GPIO0_UART0_TX: U301.4 (D); also elsewhere on the board
/GPIO1_UART0_RX: U301.1 (R); also elsewhere on the board
/GPIO10_TERM: U301.5 (TERM_TX), U301.7 (TERM_RX); also elsewhere on the board
/GPIO11_TXEN: U301.3 (DE); also elsewhere on the board
/GPIO12_RXEN: U301.2 (RE); also elsewhere on the board
GND: R301.1, R302.1, R303.1, R308.1, SW301.5, SW301.6, SW301.7, SW301.8, U301.6 (GND), U301.17 (GND); also elsewhere on the board
unnamed: D301.1 (K), R302.2
unnamed: D302.1 (K), R303.2
unnamed: D303.1 (K), R301.2
unnamed: D304.1 (K), R308.2

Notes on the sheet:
Address Config
Status LEDs
RS-422/485 Com Bus

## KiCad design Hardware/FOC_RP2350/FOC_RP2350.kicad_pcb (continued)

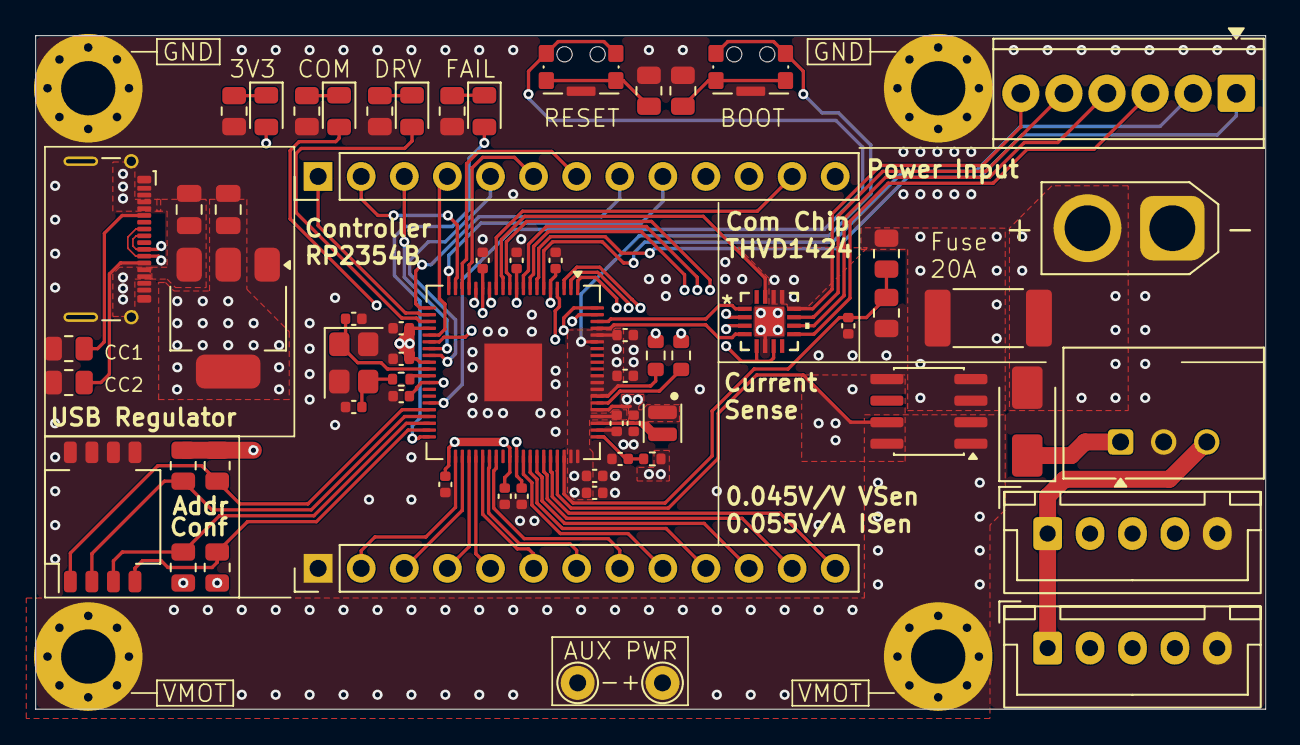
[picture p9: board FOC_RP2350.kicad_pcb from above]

Board: 4 copper layers, 72.5 x 39.7 mm, 68 parts (0 on the bottom side), 78 nets.

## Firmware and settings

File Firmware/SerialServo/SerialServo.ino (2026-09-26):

#include "ControlBoard_RP2354.h"
#include "MotorBoard_DRV8323.h"
#include "SerialDriveMotor.h"

// Configuration & tuning for DFRobot FIT1035
ControlBoard cb;                                                        // Control Board hardware class
MotorBoard mb;                                                          // Motor Board hardware class
BLDCMotor m0 = BLDCMotor(7, 10.7, 110, 0.0053);
BLDCMotor m1 = BLDCMotor(7, 10.7, 110, 0.0053);
MagneticSensorI2C enc0 = MagneticSensorI2C( AS5600_I2C );
MagneticSensorI2C enc1 = MagneticSensorI2C( AS5600_I2C );
SerialDriveMotor axis0 (m0, enc0, mb.drv0, Wire);
SerialDriveMotor axis1 (m1, enc1, mb.drv1, Wire1);
repeating_timer_t focTimer;

///////////////////////////////////////////////////////////////////////////////////////////////////////////////////////////////////////////
// RTOS Tasks
///////////////////////////////////////////////////////////////////////////////////////////////////////////////////////////////////////////

bool focTimerCB(repeating_timer_t *timer) {                             // Timer-Controlled Hard Realtime motion control loop
  axis0.loop();                                                         // Run axis loop
  return true;                                                          // Return "keep repeating" to controlling timer
}

void processCommand(Stream& ser) {                                      // Command processing accepts serial stream to allow USB and UART
  String command;                                                       // String to store the command substring
  String response;                                                      // String to store the command response
  String received = ser.readStringUntil('\n');                          // Read data from serial
  received.trim();                                                      // Remove termination characters
  if (received.length() == 0) { return; }                               // Abort if length is 0 (e.g. only newline received)
  if (received.indexOf(' ') == -1) { command = received; }              // If there is no space, the entire string is the command
  else { command = received.substring(0, received.indexOf(' ')); }      // If there is a space, first substring is the command
  command.trim();                                                       // Trim command string
  command.toUpperCase();                                                // Convert command string to uppercase for robustness

  if (command == "ENABLE") { mb.enableDrives(); }                       // Motor Driver Enable command

  if (command == "DISABLE") { mb.disableDrives(); }                     // Motor Driver Disable (coast) command

  if (command == "T") {                                                 // Torque (current) command
    int p1 = received.indexOf(' ');                                     // Find position of first space
    int p2 = received.indexOf(' ', p1 + 1);                             // Find position of second space
    int axis = received.substring(p1 + 1, p2).toInt();                  // Substring 1 is axis number
    float current = received.substring(p2 + 1).toFloat();               // Substring 2 is torque target
    if (axis == 0) { axis0.setTrkTarget(current); }                     // Apply command to the relevant axis
    if (axis == 1) { axis0.setTrkTarget(current); }
  }

  if (command == "V") {                                                 // Velocity command
    int p1 = received.indexOf(' ');                                     // Find position of first space
    int p2 = received.indexOf(' ', p1 + 1);                             // Find position of second space
    int axis = received.substring(p1 + 1, p2).toInt();                  // Substring 1 is axis number
    float velocity = received.substring(p2 + 1).toFloat();              // Substring 2 is velocity target
    if (axis == 0) { axis0.setVelTarget(velocity); }                    // Apply command to the relevant axis
    if (axis == 1) { axis0.setVelTarget(velocity); }
  }

  if (command == "P") {                                                 // Position command
    int p1 = received.indexOf(' ');                                     // Find position of first space
    int p2 = received.indexOf(' ', p1 + 1);                             // Find position of second space
    int axis = received.substring(p1 + 1, p2).toInt();                  // Substring 1 is axis number
    float position = received.substring(p2 + 1).toFloat();              // Substring 2 is position target
    if (axis == 0) { axis0.setPosTarget(position); }                    // Apply command to the relevant axis
    if (axis == 1) { axis0.setPosTarget(position); }
  }

  if (command == "C") {                                                 // Cascaded position command
    int p1 = received.indexOf(' ');                                     // Find position of first space
    int p2 = received.indexOf(' ', p1 + 1);                             // Find position of second space
    int p3 = received.indexOf(' ', p2 + 1);                             // Find position of third space
    int p4 = received.indexOf(' ', p3 + 1);                             // Find position of fourth space
    int axis = received.substring(p1 + 1, p2).toInt();                  // Substring 1 is axis number
    float position = received.substring(p2 + 1).toFloat();              // Substring 2 is position target
    float vel_ff = received.substring(p3 + 1).toFloat();                // Substring 3 is velocity feed-forward
    float trk_ff = received.substring(p4 + 1).toFloat();                // Substring 4 is torque feed-forward
    if (axis == 0) { axis0.setCascadeTargets(position,vel_ff,trk_ff); } // Apply command to the relevant axis
    if (axis == 1) { axis0.setCascadeTargets(position,vel_ff,trk_ff); }
  }

    if (command == "B") {                                               // Feedback request (Kinematics)
    int p1 = received.indexOf(' ');                                     // Find position of first space
    uint8_t power = received.substring(p1 + 1).toInt();                 // Substring 1 is braking power
    mb.setBrakeDuty(power, cb.readVoltage());                           // Apply braking power
  }

  if (command == "F") {                                                 // Feedback request (Kinematics)
    int p1 = received.indexOf(' ');                                     // Find position of first space
    int axis = received.substring(p1 + 1).toInt();                      // Substring 1 is axis number
    if (axis == 0) { response = axis0.getKinematicData(); }             // Apply command to the relevant axis
    if (axis == 1) { response = axis1.getKinematicData(); }
  }

  if (command == "FMP") {                                               // Feedback Request (Motor Power)
    int p1 = received.indexOf(' ');                                     // Find position of first space
    int axis = received.substring(p1 + 1).toInt();                      // Substring 1 is axis number
    if (axis == 0) { response = axis0.getTelemetryData(); }             // Apply command to the relevant axis
    if (axis == 1) { response = axis0.getTelemetryData(); }
  }

  if (command == "FBP") {                                               // Feedback Request (Board Power)
    response += String(cb.readCurrent(), 2);                            // Get amperage
    response += "A ";                                                   // Add unit and space
    response += String(cb.readVoltage(), 2);                            // Get voltage
    response += "V ";                                                   // Add unit and space
    response += String(cb.readVoltage()*cb.readCurrent(), 2);           // Calculate power
    response += "W";                                                    // Add unit
  }

  if (response.length() > 0) { ser.println(response); }                 // Print the response if there is one
}

void comRxTask(void *parameter) {                                       // COM RX: receive commands and call processing
  for (;;) {                                                            // Let Task run forever
    vTaskDelay(pdMS_TO_TICKS(10));                                      // Short delay to avoid excessive CPU load
    bool usbAvail = Serial.available();                                 // Check if data is available on USB Serial
    bool comAvail = cb.comchipUART.available();                         // Check if data is available on RS422/485
    bool ttlAvail = cb.ttlUART.available();                             // Check if data is available on TTL UART
    cb.setComLED(usbAvail || comAvail || ttlAvail);                     // Set LED to indicate data available
    if ( usbAvail ) processCommand(Serial);                             // If data is available on USB: pass SerialUSB object
    if ( comAvail ) processCommand(cb.comchipUART);                     // If data is available on 485: pass SerialUART object
    if ( ttlAvail ) processCommand(cb.ttlUART);                         // If data is available on TTL: pass SerialUART object
  }
}

void dataUpdateTask(void *parameter) {                                  // Data update: slower functions
  TickType_t lastWakeTime = xTaskGetTickCount();                        // last time the task was executed
  for (;;) {                                                            // Let Task run forever
    axis0.updateTelemetry();                                            // Update telemetry data for axis 0
    axis1.updateTelemetry();                                            // Update telemetry data for axis 1
    vTaskDelayUntil(&lastWakeTime, pdMS_TO_TICKS(100));                 // Delay task until 100ms after last start
  }
}

///////////////////////////////////////////////////////////////////////////////////////////////////////////////////////////////////////////
// Flow Control
///////////////////////////////////////////////////////////////////////////////////////////////////////////////////////////////////////////

void setup() {  
  cb.begin();                                                           // Initialize control board
  mb.begin(cb.readVoltage(),cb.readVoltage());                          // Initialize motor board
  mb.enableDrives();                                                    // Start up drivers for configuration
  axis0.setup();                                                        // Run servo axis setup
  axis0.setLimits(0.5, 20);                                             // Servo axis: 0.5A and 20rad/s limit
  axis0.tuneFilter(0.005, NOT_SET);                                     // Servo axis: 5ms filter time, no fixed sample time
  axis0.tuneVelController(0.01,1,0,1000);                               // Servo axis: PID values and ramp rate for velocity controller
  axis0.tunePosController(20, 0, 0, NOT_SET);                           // Servo axis: PID values and ramp rate for position controller
  mb.disableDrives();                                                   // Disable drivers until called to run
  add_repeating_timer_us(-1000, focTimerCB, nullptr, &focTimer);        // Initialize task: FOC (timer controlled)
  xTaskCreate(comRxTask,"COM RX",2048,nullptr,2,nullptr);               // RTOS Receive & Forward Task
  xTaskCreate(dataUpdateTask,"Telemetry",2048,nullptr,3,nullptr);       // Low Speed Updates Task
}

void loop() {
  delay(1000);                                                          // Loop does nothing, tasks are controlled by FreeRTOS
}

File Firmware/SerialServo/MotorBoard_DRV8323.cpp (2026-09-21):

#include "MotorBoard_DRV8323.h"

///////////////////////////////////////////////////////////////////////////////////////////////////////////////////////////////////////////
// DRV8323S SPI driver definition and setup
///////////////////////////////////////////////////////////////////////////////////////////////////////////////////////////////////////////

DRV8323S_SPI::DRV8323S_SPI(uint8_t sclk,uint8_t sdi,uint8_t sdo,uint8_t cs) : _sclk(sclk),_sdi(sdi),_sdo(sdo),_cs(cs) { }

void DRV8323S_SPI::begin() {                                                  // SPI driver setup function
  pinMode(_sclk, OUTPUT);                                                     // Pin config: DRV8323 clock in, MCU clock out
  pinMode(_sdi, OUTPUT);                                                      // Pin config: DRV8323 data in, MCU data out
  pinMode(_sdo, INPUT_PULLUP);                                                // Pin config: DRV8323 data out, MCU data in
  pinMode(_cs, OUTPUT);                                                       // Pin config: Chip select (active low)
  digitalWrite(_sclk, LOW);                                                   // Pin state: low, DRV8323 requires SCLK LOW when nSCS changes
  digitalWrite(_sdi, LOW);                                                    // Pin state: low, indicates zero
  digitalWrite(_cs, HIGH);                                                    // Pin state: high, deselect chip (idle)
}

///////////////////////////////////////////////////////////////////////////////////////////////////////////////////////////////////////////
// High-Level SPI Control
///////////////////////////////////////////////////////////////////////////////////////////////////////////////////////////////////////////

uint16_t DRV8323S_SPI::writeRegister(uint8_t reg, uint16_t data) {            // Write a register on the device
  uint16_t tx = ((uint16_t)(reg & 0x0F) << 11) | (data & 0x07FF);             // B15 = 0 (write), B14:11 = register address, B10:0 = register data
  select();                                                                   // Select chip (and ensure it's enabled)
  uint16_t rx = transfer16(tx);                                               // Send data, register response
  deselect();                                                                 // Deselect chip (and disable if it was previously disabled)
  return rx;                                                                  // Return received data
}

///////////////////////////////////////////////////////////////////////////////////////////////////////////////////////////////////////////

uint16_t DRV8323S_SPI::readRegister(uint8_t reg) {                            // Read a register on the device
  uint16_t tx = 0x8000 | ((uint16_t)(reg & 0x0F) << 11);                      // B15 = 1 (read), B14:11  = register address, B10:0 = don't care (device returns data)
  select();                                                                   // Select chip (and ensure it's enabled)
  uint16_t rx = transfer16(tx);                                               // Send data, register response
  deselect();                                                                 // Deselect chip (and disable if it was previously disabled)
  return rx;                                                                  // Return received data
}

///////////////////////////////////////////////////////////////////////////////////////////////////////////////////////////////////////////
// Low-Level SPI Control
///////////////////////////////////////////////////////////////////////////////////////////////////////////////////////////////////////////

void DRV8323S_SPI::select() {                                                 // Function to select the chip
  digitalWrite(_sclk, LOW);                                                   // SCLK must already be LOW.
  digitalWrite(_cs, LOW);                                                     // nSCS setup time >= 50 ns.
}

///////////////////////////////////////////////////////////////////////////////////////////////////////////////////////////////////////////

void DRV8323S_SPI::deselect() {                                               // Function to deselect the chip
  digitalWrite(_sclk, LOW);                                                   // SCLK must be LOW when nSCS goes HIGH.
  digitalWrite(_cs, HIGH);                                                    // Datasheet requires nSCS HIGH for >= 400 ns between SPI words.      
}

///////////////////////////////////////////////////////////////////////////////////////////////////////////////////////////////////////////
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

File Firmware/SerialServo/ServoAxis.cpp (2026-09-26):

#include "ServoAxis.h"

ServoAxis::ServoAxis  (BLDCMotor &motor, MagneticSensorI2C &encoder, BLDCDriver3PWM &driver, TwoWire &wire)
                      : motor(motor), encoder(encoder), driver(driver), wire(wire) {}

///////////////////////////////////////////////////////////////////////////////////////////////////////////////////////////////////////////
// Controller tuning function
///////////////////////////////////////////////////////////////////////////////////////////////////////////////////////////////////////////

void ServoAxis::tuneFilter(float tf, float ts) {
  motor.LPF_velocity.Tf = tf;                                         // Filter time constant
  motor.LPF_velocity.Ts = ts;                                         // Sampling time
}

void ServoAxis::tuneVelController(float p, float i, float d, float ramp) {
  motor.PID_velocity.P = p;                                           // Proportional gain
  motor.PID_velocity.I = i;                                           // Integral gain
  motor.PID_velocity.D = d;                                           // Derivative gain
  motor.PID_velocity.output_ramp = ramp;                              // Voltage ramp rate ~ jerk limit
}

void ServoAxis::tunePosController(float p, float i, float d, float ramp) {
  motor.P_angle.P = p;                                                // Proportional gain
  motor.P_angle.I = i;                                                // Integral gain
  motor.P_angle.D = d;                                                // Derivative gain
  motor.P_angle.output_ramp = ramp;                                   // Velocity ramp rate ~ acceleration limit
}

///////////////////////////////////////////////////////////////////////////////////////////////////////////////////////////////////////////
// Telemetry functions
///////////////////////////////////////////////////////////////////////////////////////////////////////////////////////////////////////////

void ServoAxis::updateTelemetry() {                                   // Internally update the motor's telemetry data
  float vq = motor.voltage.q;                                         // Motor Q (torque producing) voltage
  float vd = motor.voltage.d;                                         // Motor D (field producing) voltage
  telemetry.amps = motor.current.q;                                   // Motor Q current = total current (no lag compensation)
  telemetry.volts = sqrt(vd * vd + vq * vq);                          // Total commanded voltate according to Pytagoras theorem
  telemetry.watts = telemetry.amps * telemetry.volts;                 // Power according to Ohm's law
  telemetry.vel = motor.shaft_velocity;                               // Rotational velocity (rad/s)
  telemetry.angle = motor.shaft_angle;                                // Angle (rad)
}

String ServoAxis::getKinematicData() {                                // Get the motor's telemetry data regarding motion control
  String result;                                                      // String to store the result
  result += String(telemetry.vel, 2);                                 // Get velocity
  result += " ";                                                      // Add a space
  result += String(telemetry.angle, 2);                               // Get position
  return result;                                                      // Return the string
}

String ServoAxis::getTelemetryData() {                                // Get the motor's telemetry data regarding electrical power
  String result;                                                      // String to store the result
  result += String(telemetry.amps, 2);                                // Get commanded amperage
  result += "A ";                                                     // Add unit and space
  result += String(telemetry.volts, 2);                               // Get commanded voltage
  result += "V ";                                                     // Add unit and space
  result += String(telemetry.watts, 2);                               // Get calculated power
  result += "W";                                                      // Add unit
  return result;                                                      // Return the string
}

///////////////////////////////////////////////////////////////////////////////////////////////////////////////////////////////////////////
// Control functions
///////////////////////////////////////////////////////////////////////////////////////////////////////////////////////////////////////////

void ServoAxis::setTrkTarget(float trk) {                             // Torque command
  motor.updateMotionControlType(MotionControlType::torque);           // Switch to torque control mode
  motor.target = trk;                                                 // Update torque target
}

void ServoAxis::setVelTarget(float vel) {                             // Velocity command
  motor.updateMotionControlType(MotionControlType::velocity);         // Switch to velocity control mode
  motor.target = vel;                                                 // Update velocity target
}

void ServoAxis::setPosTarget(float pos) {                             // Position (no cascade) command
  motor.updateMotionControlType(MotionControlType::angle_nocascade);  // Switch to direct angle control mode
  motor.target = pos;                                                 // Update angle target
}

void ServoAxis::setCascadeTargets(float pos, float vel, float trk) {  // Position (cascaded) command
  motor.updateMotionControlType(MotionControlType::angle);            // Switch to cascaded angle control mode
  motor.target = pos;                                                 // Update angle target
  motor.feed_forward_velocity = vel;                                  // Set velocity feed-forward
  motor.feed_forward_current.q = trk;                                 // Set current (torque) feed-forward
}

void ServoAxis::setLimits(float current, float velocity) {
  motor.updateCurrentLimit(current);                                  // Motor current (torque) limit
  motor.updateVelocityLimit(velocity);                                // Motor velocity limit
}

///////////////////////////////////////////////////////////////////////////////////////////////////////////////////////////////////////////
// Setup & Loop functions
///////////////////////////////////////////////////////////////////////////////////////////////////////////////////////////////////////////
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

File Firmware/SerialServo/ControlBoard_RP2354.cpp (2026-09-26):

#include "ControlBoard_RP2354.h"

///////////////////////////////////////////////////////////////////////////////////////////////////////////////////////////////////////////
// Control Board definition and setup
///////////////////////////////////////////////////////////////////////////////////////////////////////////////////////////////////////////

ControlBoard::ControlBoard() :  ttlUART(Serial2),                               // Assign UART1 to TTL UART
                                comchipUART(Serial1)                            // Assign UART0 to RS422/RS485 UART
{ }                                                                             // Constructor empty

void ControlBoard::begin() {                                                    // Board initializer functions
  for (int i = 0; i < 4; i++) { pinMode(CONFSW[i], INPUT); }                    // Configure conf sw inputs
  pinMode(LED_DRV, OUTPUT);                                                     // Configure drive LED control
  pinMode(LED_COM, OUTPUT);                                                     // Configure communication LED control
  pinMode(COMBUS_TXEN, OUTPUT);                                                 // Configure transceiver Tx Enable
  pinMode(COMBUS_RXEN, OUTPUT);                                                 // Configure transceiver Rx Enable
  pinMode(COMBUS_TERM, OUTPUT);                                                 // Configure transceiver Termination Resistor
  pinMode(COMBUS_HF, OUTPUT);                                                   // Configure transceiver Half/Full Duplex Switch
  comchipConfig(BUSIDLE);                                                       // Initial config: Rx/Tx disabled
  analogReadResolution(12);                                                     // Configure ADC
  ttlUART.setRX(EXTCOM_RX);                                                     // Configure TTL UART Pins
  ttlUART.setTX(EXTCOM_TX);                                                     // Configure TTL UART Pins
  ttlUART.begin(115200);                                                        // Begin TTL UART
  comchipUART.setRX(COMBUS_RX);                                                 // Configure RS422/RS485 UART Pins
  comchipUART.setTX(COMBUS_TX);                                                 // Configure RS422/RS485 UART Pins
  comchipUART.begin(10000000);                                                  // Begin RS422/RS485 UART
  Serial.begin(115200);                                                         // Begin USB Serial
}

///////////////////////////////////////////////////////////////////////////////////////////////////////////////////////////////////////////
// Low-Level Communication Chip control
///////////////////////////////////////////////////////////////////////////////////////////////////////////////////////////////////////////

void ControlBoard::comchipConfig(int txen, int rxen, int term, int halfd) {
  digitalWrite(COMBUS_TXEN, txen);                                              // Transmitter enable
  digitalWrite(COMBUS_RXEN, 1 - rxen);                                          // Receiver enable (inverted on hardware)
  digitalWrite(COMBUS_TERM, term);                                              // Termination resistor enable
  digitalWrite(COMBUS_HF, halfd);                                               // Half-Duplex enable
}

///////////////////////////////////////////////////////////////////////////////////////////////////////////////////////////////////////////
// Input evaluation functions
///////////////////////////////////////////////////////////////////////////////////////////////////////////////////////////////////////////

float ControlBoard::readCurrent() {                                             // Read supply current
  float voltage = analogRead(INPUT_CURR) * 3.3f / 4095.0f;                      // Get ADC voltage
  float current = (voltage - 1.65f) / 0.055f;                                   // Convert voltage to current
  return -current;                                                              // Return the calculated current
}

float ControlBoard::readVoltage() {                                             // Read supply voltage
  float adcVoltage = analogRead(INPUT_VOLT) * 3.3f / 4095.0f;                   // Get ADC voltage
  float motorVoltage = adcVoltage * (10000.0f + 470.0f) / 470.0f;               // Convert to voltage above divider
  return motorVoltage;                                                          // Return the calculated voltage
}
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

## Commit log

2026-09-04 Added KiCAD Projects
    [FOC_DRV8323.kicad_pcb, FOC_DRV8323.kicad_sch, FOC_RP2350.kicad_pcb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]
2026-09-04 Added test sketch for controller boards
2026-09-12 Hardware update
    - Removed 5V net as it is not really needed for typical SimpleFOC encoders. This reduces part cost a lot.
    - Fixed SPI pin assignment
    - Exposed another GPIO pin in place of the +5V pin
    - Boards changed to transfer power via the standoff pads instead of a solder connection
    - Moved accelerometer to the controller board
    - Resistance changes to reduce BOM
    - Replaced encoder connection with JST-XH
    [FOC_DRV8323.kicad_pcb, FOC_DRV8323.kicad_sch, FOC_RP2350.kicad_pcb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]
2026-09-19 Driver redesign to allow 8323H and 8323S
    [FOC_DRV8323.kicad_pcb, FOC_DRV8323.kicad_sch, FOC_RP2350.kicad_pcb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]
2026-09-20 Added DRV8323S SPI driver
    - Driver chip can now be controlled over SPI (allowing control of the custom driver board)
    - Minor updates to control board definition
2026-09-21 Added second driver option (high-power shield) to hardware
    [FOC_DualDRV8323.kicad_pcb, FOC_DualDRV8323.kicad_sch, FOC_PowerDRV8323.kicad_pcb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]
2026-09-21 Revise README for improved clarity and structure
    Updated the README to enhance clarity and organization, adding sections for the base board, dual BLDC driver board, and high-power BLDC driver board.
2026-09-26 First version of serial control firmware
    [FOC_DualDRV8323.kicad_pcb, FOC_DualDRV8323.kicad_sch, FOC_PowerDRV8323.kicad_pcb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]
